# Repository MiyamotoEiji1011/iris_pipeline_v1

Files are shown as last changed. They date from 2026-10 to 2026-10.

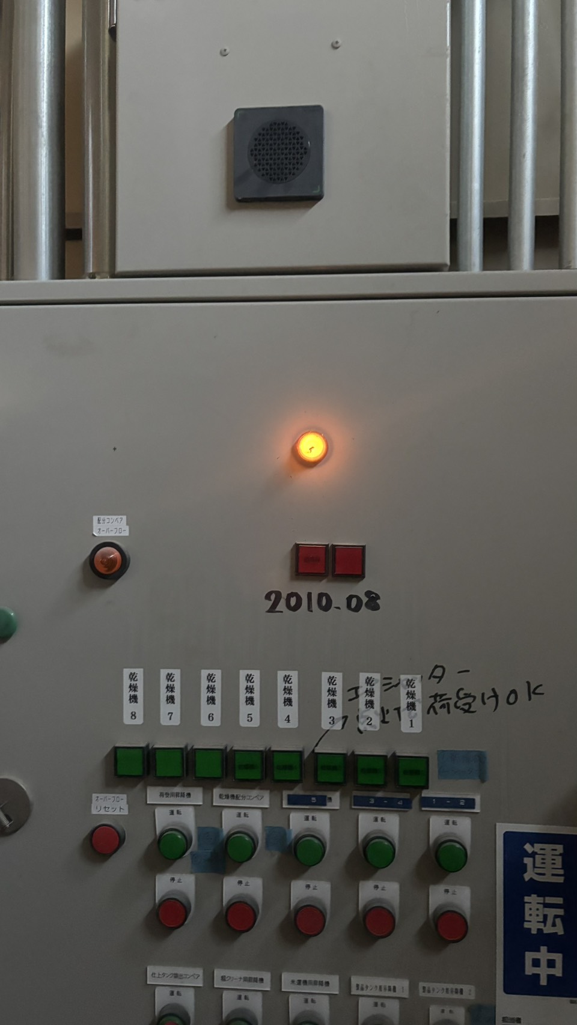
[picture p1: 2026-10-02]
画像/S__83599375_0.jpg

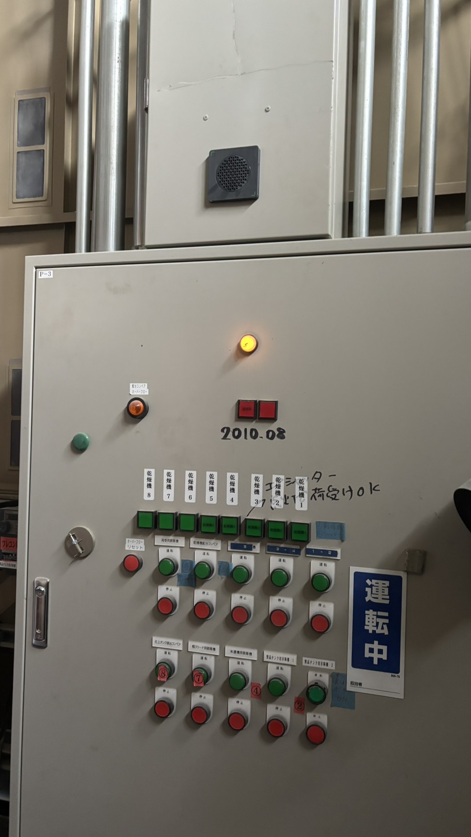
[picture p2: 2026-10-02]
画像/S__83599382_0.jpg

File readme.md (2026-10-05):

# iris pipeline v1
空調設備管理デバイス
各空調機（エアコン）の温度を計測し、空調設備の電力効率向上を目的として、必要に応じてミストを噴射し、銅管温度を低下させるデバイスです。
温度センサから取得した測定値をもとに電磁弁を自動制御し、設定された温度条件に応じてミストの噴射・停止を行います。

※温度センサについて
各空調機に2台のセンサを使用する。
銅管と空気の吸気部分の2か所に配置して温度を測定する。
電磁弁の制御に使用する値はwebアプリ側で切り替えれるようにする。

# 配線
## 温度センサ(DS18B20)
GPIO04=sensor_A1,sensor_A2
GPIO05=sensor_B1,sensor_B2
GPIO06=sensor_C1,sensor_C2

GPIO12=sensor_D1,sensor_D2
GPIO13=sensor_E1,sensor_E2
GPIO16=sensor_F1,sensor_F2

GPIO17=sensor_G1,sensor_G2
GPIO18=sensor_H1,sensor_H2
GPIO19=sensor_I1,sensor_I2

GPIO20=sensor_J1,sensor_J2
GPIO21=sensor_K1,sensor_K2
GPIO26=sensor_L1,sensor_L2
## 電磁バルブ(12V)
リレーモジュールに接続(8つ)
## リレーモジュール(リレー*8)
GPIO07=relay_A
GPIO08=relay_B
GPIO09=relay_C
GPIO10=relay_D
GPIO11=relay_E
GPIO22=relay_F
GPIO23=relay_G
GPIO24=relay_H
## LED
GPIO25=DAEMON_LED
GPIO27=API_LED
GPIO14=NETWORK_LED
## SW
GPIO15=Reset_SW

# webアプリ
githubPagesをもちいて、ラズパイ側のッデータの受け取りや設定の書き換えなどを行う。APIを使用してユーザーが任意のタイミングでリクエストができるようにする。常時通信は行わない。

# コード
## main
tools,systemを使用して制御を行う。

## tools
・read_temp_sensor.py
read_temp_sensor(GPIO)->list(float)
任意のGPIOの温度センサーの値を取得可能できる数取得し返す。
・write_relay_module.py
write_relay_module(GPIO,bool)->bool()
リレーモジュールのGPIOのHIGH/LOWを切り替える
・write_temp_date.py
write_temp_date()->xlsx
指定の形式で温度データを渡すことでエクセルファイル追加保存する。また、エクセルファイルの新規作成などの関数もある。
・write_log.py
write_log()->txt
各、処理のログなどをすべて時間とともに保存する。
最大1000行までのログを記載し、超える場合は古い記録と入れ替える。

## api
未定

## system
・read_network.py
ネットワーク接続状態を確認する。
・read_api.py
外部アプリからの接続や編集を管理
・read_reset_switch.py
デーモンを終了し、システムを再起動
・read_system.py
OSの状態を管理

## config
・attach_pin.json
各GPIOのピン設定などを名前付けして定義づける。main.pyは起動時にこのファイルから読み込んだPINを使用して制御を行う。また、温度センサーの識別IDも記載。
・date_config.json
データの読み取り間隔などデータの記録に関する定義を保存するファイル。
・process_config.json
各電磁弁の開閉温度の設定、各空調機の制御で銅管温度と吸気温度のどちらを設定しているのかを保存しているファイル。
・config
　githubなどのアカウント関係に紐づく値を管理

# raspi
cd ~/iris_pipeline_v1/raspi
git pull
source .venv/bin/activate
pip install -r requirements.txt

## git
cd ~/iris_pipeline_v1
git add .
git commit -m "update raspi code"
git push

## デーモン（systemd）

### 初回登録
```bash
sudo cp ~/iris_pipeline_v1/raspi/iris_pipeline.service /etc/systemd/system/
sudo systemctl daemon-reload
sudo systemctl enable iris_pipeline
sudo systemctl start iris_pipeline
```

### 状態確認
```bash
sudo systemctl status iris_pipeline
```

### ログ確認
```bash
journalctl -u iris_pipeline -f
```

### 停止 / 起動 / 再起動
```bash
sudo systemctl stop iris_pipeline
sudo systemctl start iris_pipeline
sudo systemctl restart iris_pipeline
```

### 自動起動の無効化
```bash
sudo systemctl disable iris_pipeline
```

### コード更新後の反映手順
```bash
cd ~/iris_pipeline_v1
git pull
sudo systemctl restart iris_pipeline
```

## システム監視デーモン（iris_system）

ネットワーク状態 LED と リセット SW を管理する独立デーモン。

### sudo reboot の許可設定（初回のみ）
```bash
sudo visudo
```
以下の行を末尾に追加して保存：
```
pi ALL=(ALL) NOPASSWD: /sbin/reboot
```

### 初回登録
```bash
sudo cp ~/iris_pipeline_v1/raspi/iris_system.service /etc/systemd/system/
sudo systemctl daemon-reload
sudo systemctl enable iris_system
sudo systemctl start iris_system
```

### 状態確認 / ログ
```bash
sudo systemctl status iris_system
journalctl -u iris_system -f
```

### 停止 / 起動 / 再起動
```bash
sudo systemctl stop iris_system
sudo systemctl start iris_system
sudo systemctl restart iris_system
```

### コード更新後の反映手順
```bash
cd ~/iris_pipeline_v1
git pull
sudo systemctl restart iris_system
```

# webapp
https://miyamotoeiji1011.github.io/iris_pipeline_v1/

# Tailscale
IPの確認
tailscale ip -4

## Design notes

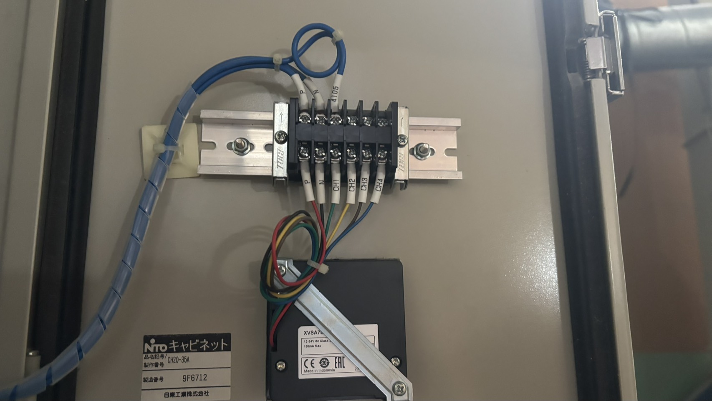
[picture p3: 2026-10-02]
画像/S__83599379_0.jpg

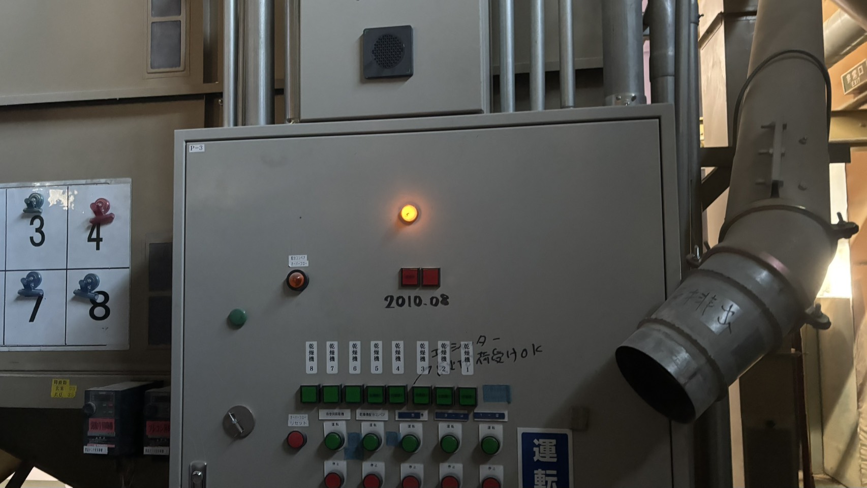
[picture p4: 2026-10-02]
画像/S__83599374_0.jpg

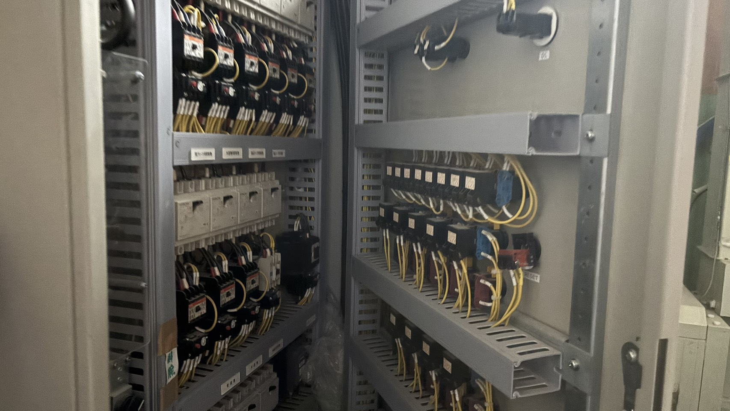
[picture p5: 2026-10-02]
画像/S__83599384_0.jpg

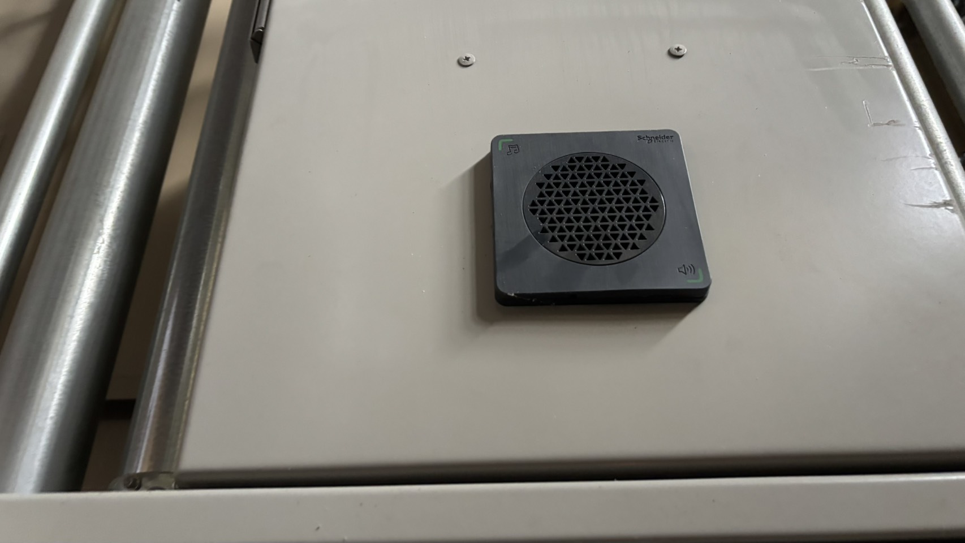
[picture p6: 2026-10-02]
画像/S__83599381_0.jpg

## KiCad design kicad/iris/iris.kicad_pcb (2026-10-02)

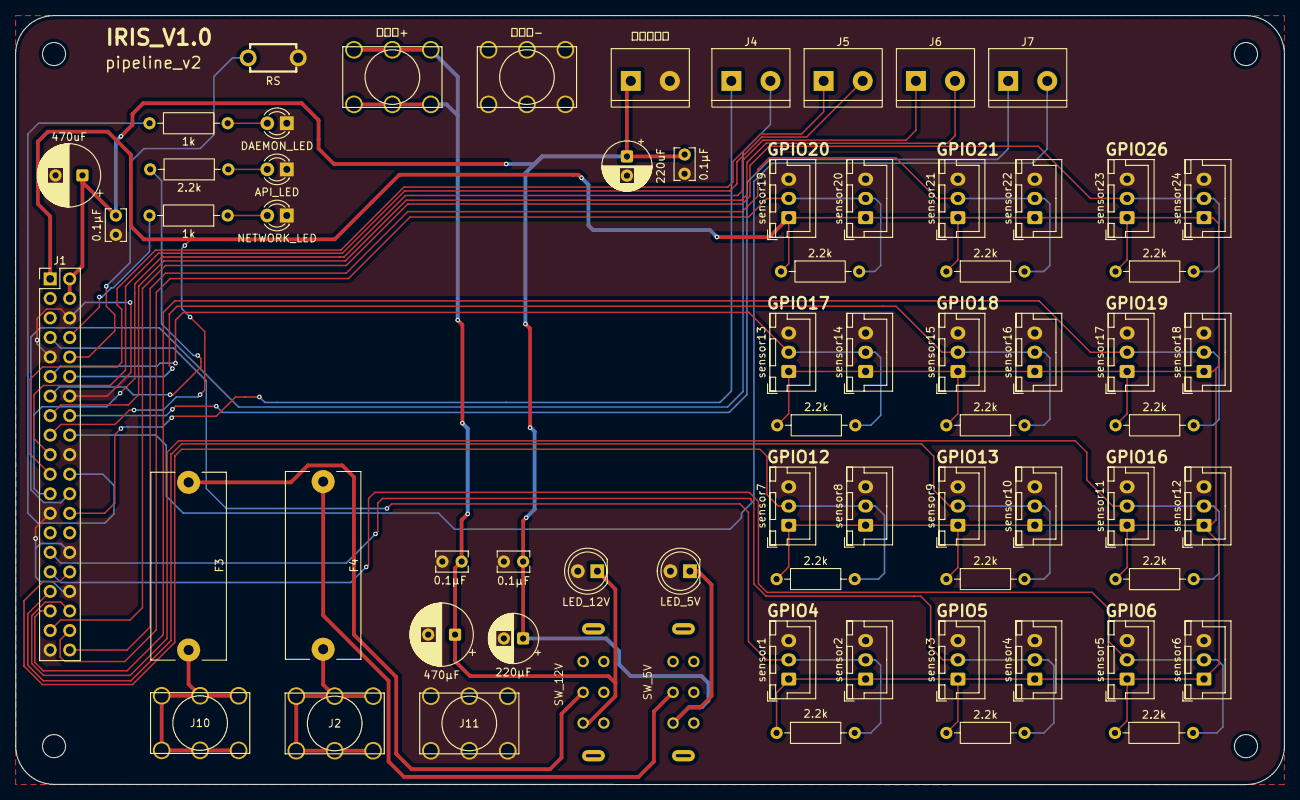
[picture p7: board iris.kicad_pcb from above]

Board: 2 copper layers, 165.0 x 100.0 mm, 68 parts (0 on the bottom side), 35 nets.

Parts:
0.1µF, 0.1µF#2, 0.1µF#3, 0.1µF#4: 0.1µF; C_Rect_L4.0mm_W2.5mm_P2.50mm
1k, 1k#2: 1k; R_Axial_DIN0207_L6.3mm_D2.5mm_P10.16mm_Horizontal
2.2k, 2.2k#2, 2.2k#3, 2.2k#4, 2.2k#5, 2.2k#6, 2.2k#7, 2.2k#8, 2.2k#9, 2.2k#10, 2.2k#11, 2.2k#12, 2.2k#13: 2.2k; R_Axial_DIN0207_L6.3mm_D2.5mm_P10.16mm_Horizontal
220uF: 220uF; CP_Radial_D6.3mm_P2.50mm
220µF: 220µF; CP_Radial_D6.3mm_P2.50mm
470uF: 470uF; CP_Radial_D8.0mm_P3.50mm
470µF: 470µF; CP_Radial_D8.0mm_P3.50mm
API_LED: API_LED; LED_D3.0mm
DAEMON_LED: DAEMON_LED; LED_D3.0mm
F3, F4: Fuse; Fuseholder_Cylinder-5x20mm_MF-563
J1: Conn_02x20_Odd_Even; PinHeader_2x20_P2.54mm_Vertical
J2: 電源5V; PCB-20(632)F
J4, J5, J6, J7: 信号ターミナル; TerminalBlock_Alphaplus_TB111-2-2-E-1-1_1x02_P5.08_Horizont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
J10: 電源12V; PCB-20(632)F
J11: 電源GND; PCB-20(632)F
LED_5V: OSG8NU5B64A-5V; LED_D5.0mm
LED_12V: OSG8NU5B64A-12V; LED_D5.0mm
NETWORK_LED: NETWORK_LED; LED_D3.0mm
RS: SW_Push; sw_TVBP06-B043CB-B
SW_5V, SW_12V: SW_DPDT_x2; SS22F06G5-G
sensor1, sensor2, sensor3, sensor4, sensor5, sensor6, sensor7, sensor8, sensor9, sensor10, sensor11, sensor12, sensor13, sensor14, sensor15, sensor16, sensor17, sensor18, sensor19, sensor20, sensor21, sensor22, sensor23, sensor24: B3B-XH-A(LF)(SN); JST_XH_B3B-XH-A_1x03_P2.50mm_Vertical
リレー電源: リレー電源ターミナル; TerminalBlock_Alphaplus_TB111-2-2-E-1-1_1x02_P5.08_Horizont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
電磁弁+: 電磁弁+; PCB-20(632)F
電磁弁-: 電磁弁-; PCB-20(632)F

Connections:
+3V3: 2.2k.1, 2.2k#2.1, 2.2k#3.1, 2.2k#4.1, 2.2k#6.1, 2.2k#7.1, 2.2k#8.1, 2.2k#9.1, 2.2k#10.1, 2.2k#11.1, 2.2k#12.1, 2.2k#13.1, J1.1, J1.17, sensor1.1, sensor2.1, sensor3.1, sensor4.1, sensor5.1, sensor6.1, sensor7.1, sensor8.1, sensor9.1, sensor10.1, sensor11.1, sensor12.1, sensor13.1, sensor14.1, sensor15.1, sensor16.1, sensor17.1, sensor18.1, sensor19.1, sensor20.1, sensor21.1, sensor22.1, sensor23.1, sensor24.1
+5V: 0.1µF#2.1, 0.1µF#3.1, 0.1µF#4.1, 220uF.1, 220µF.1, 470uF.1, J1.2, J1.4, LED_5V.1 (K), SW_5V.1 (A), リレー電源.1
+12V: 0.1µF.1, 470µF.1, LED_12V.1 (K), SW_12V.1 (A), 電磁弁+.1
GND: 0.1µF.2, 0.1µF#2.2, 0.1µF#3.2, 0.1µF#4.2, 220uF.2, 220µF.2, 470uF.2, 470µF.2, API_LED.1 (K), DAEMON_LED.1 (K), J1.6, J1.9, J1.14, J1.20, J1.25, J1.30, J1.34, J1.39, J11.1, LED_5V.2 (A), LED_12V.2 (A), NETWORK_LED.1 (K), RS.2, sensor1.3, sensor2.3, sensor3.3, sensor4.3, sensor5.3, sensor6.3, sensor7.3, sensor8.3, sensor9.3, sensor10.3, sensor11.3, sensor12.3, sensor13.3, sensor14.3, sensor15.3, sensor16.3, sensor17.3, sensor18.3, sensor19.3, sensor20.3, sensor21.3, sensor22.3, sensor23.3, sensor24.3, リレー電源.2, 電磁弁-.1
GPIO4: 2.2k#9.2, J1.7, sensor1.2, sensor2.2
GPIO5: 2.2k.2, J1.29, sensor3.2, sensor4.2
GPIO6: 2.2k#12.2, J1.31, sensor5.2, sensor6.2
GPIO7: J1.26, J4.1
GPIO8: J1.24, J4.2
GPIO9: J1.21, J5.1
GPIO10: J1.19, J5.2
GPIO11: J1.23, J6.1
GPIO12: 2.2k#7.2, J1.32, sensor7.2, sensor8.2
GPIO13: 2.2k#2.2, J1.33, sensor9.2, sensor10.2
GPIO14: 1k#2.2, J1.8
GPIO16: 2.2k#4.2, J1.36, sensor11.2, sensor12.2
GPIO17: 2.2k#11.2, J1.11, sensor13.2, sensor14.2
GPIO18: 2.2k#6.2, J1.12, sensor15.2, sensor16.2
GPIO19: 2.2k#10.2, J1.35, sensor17.2, sensor18.2
GPIO20: 2.2k#8.2, J1.38, sensor19.2, sensor20.2
GPIO21: 2.2k#3.2, J1.40, sensor21.2, sensor22.2
GPIO22: J1.15, J6.2
GPIO23: J1.16, J7.1
GPIO24: J1.18, J7.2
GPIO25: 1k.2, J1.22
GPIO26: 2.2k#13.2, J1.37, sensor23.2, sensor24.2
GPIO27: 2.2k#5.2, J1.13
unnamed: 1k.1, DAEMON_LED.2 (A)
unnamed: 2.2k#5.1, API_LED.2 (A)
unnamed: 1k#2.1, NETWORK_LED.2 (A)
unnamed: J1.10, RS.1
unnamed: F4.1, J2.1
unnamed: F3.1, J10.1
unnamed: F4.2, SW_5V.2 (B)
unnamed: F3.2, SW_12V.2 (B)

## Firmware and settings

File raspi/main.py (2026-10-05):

import RPi.GPIO as GPIO  # type: ignore
import json
import os
import threading
import time
from datetime import datetime
from config.units import UNITS
from config.data_config import (
    CONTROL_INTERVAL, CONFIG_POLL_INTERVAL, RECORD_INTERVAL,
    STATUS_PUSH_INTERVAL, DATA_PUSH_INTERVAL,
)
from tools.read_temp_sensor import read_temp_sensor
from tools.write_relay_module import write_relay_module
from tools.write_csv import append_csv
from tools.fetch_process_config import fetch_process_config
from tools.push_status_json import push_status_json
from tools.git_push_data import git_push_data

_PROCESS_CONFIG_PATH = os.path.join(os.path.dirname(__file__), "config/process_config.json")
_DATA_DIR            = os.path.join(os.path.dirname(__file__), "../data")

DAEMON_LED_GPIO = 25
API_LED_GPIO    = 27

_applied_version: int       = 0
_pending_config:  dict | None = None
_api_led_stop:    threading.Event | None = None


def log(msg):
    print(f"[{datetime.now().strftime('%H:%M:%S')}] {msg}")


# ---------------------------------------------------------------------------
# API LED（GPIO27）点滅制御
# ---------------------------------------------------------------------------

def _blink_worker(stop_event: threading.Event):
    """別スレッドで API_LED を 0.3秒周期で点滅させる。"""
    while not stop_event.is_set():
        GPIO.output(API_LED_GPIO, True)
        stop_event.wait(0.3)
        GPIO.output(API_LED_GPIO, False)
        stop_event.wait(0.3)
    GPIO.output(API_LED_GPIO, False)


def start_api_led():
    global _api_led_stop
    if _api_led_stop is not None:
        return
    _api_led_stop = threading.Event()
    threading.Thread(target=_blink_worker, args=(_api_led_stop,), daemon=True).start()


def stop_api_led():
    global _api_led_stop
    if _api_led_stop is None:
        return
    _api_led_stop.set()
    _api_led_stop = None


# ---------------------------------------------------------------------------
# config 適用
# ---------------------------------------------------------------------------

def _apply_units_config(config: dict, apply_manual: bool = True):
    """
    config dict の内容を UNITS に適用する。
    モード変更時はリレーを安全にOFF（Desired State → Actual State の橋渡し）。

    Args:
        config:       process_config.json の内容
        apply_manual: False の場合、手動モードでも relay を ON しない（起動時用）
    """
    global _applied_version
    for unit_name, unit in UNITS.items():
        if unit_name not in config.get("units", {}):
            continue
        cfg      = config["units"][unit_name]
        new_mode = cfg["mode"]
        old_mode = unit["mode"]

        # モードが変わるときは先にリレーをOFF
        if old_mode is not None and old_mode != new_mode:
            write_relay_module(unit["relay_gpio"], False)
            unit["relay_state"] = False
            log(f"  ユニット{unit_name} モード変更 ({old_mode}→{new_mode}) 強制OFF")

        unit["label"]          = cfg.get("label", unit_name)
        unit["temp_on"]        = cfg["temp_on"]
        unit["temp_off"]       = cfg["temp_off"]
        unit["mode"]           = cfg["mode"]
        unit["manual_command"] = cfg["manual_command"]
        unit["control_sensor"] = cfg.get("control_sensor", "銅管部温度")

        # 手動モード: manual_command を即時適用（起動時は常にOFF）
        if new_mode == "manual":
            state = (cfg["manual_command"] == "ON") and apply_manual
            write_relay_module(unit["relay_gpio"], state)
            unit["relay_state"] = state
            cmd_str = "ON" if state else "OFF"
            log(f"  ユニット{unit_name} 手動コマンド適用: {cmd_str}")

    _applied_version = config.get("version", _applied_version)
    log(f"config v{_applied_version} 適用完了")


def load_process_config():
    """起動時: ローカルの process_config.json を読み込む（手動コマンドは適用しない）。"""
    with open(_PROCESS_CONFIG_PATH) as f:
        config = json.load(f)
    _apply_units_config(config, apply_manual=False)


def check_and_apply_config():
    """GitHub から設定を取得し、バージョンが新しければ pending_config にセットする。"""
    global _pending_config
    new_config = fetch_process_config()
    if new_config is None:
        return
    if new_config.get("version", 0) > _applied_version:
        _pending_config = new_config
        log(f"新しいconfig検知 v{new_config['version']} → 次の制御サイクルで適用")


# ---------------------------------------------------------------------------
# GPIO
# ---------------------------------------------------------------------------

def cleanup():
    stop_api_led()
    try:
        GPIO.output(DAEMON_LED_GPIO, False)
        GPIO.output(API_LED_GPIO, False)
    except RuntimeError:
        pass
    GPIO.cleanup()
    log("GPIO クリーンアップ完了")


def setup():
    cleanup()
    GPIO.setmode(GPIO.BCM)
    GPIO.setup(DAEMON_LED_GPIO, GPIO.OUT, initial=GPIO.LOW)
    GPIO.setup(API_LED_GPIO,    GPIO.OUT, initial=GPIO.LOW)
    GPIO.output(DAEMON_LED_GPIO, True)
    log("GPIO セットアップ完了")
    load_process_config()


# ---------------------------------------------------------------------------
# センサ・制御
# ---------------------------------------------------------------------------

def temp_sensor() -> list[dict]:
    log("----温度センサ----")
    results = []
    for unit_name, unit in UNITS.items():
        for r in read_temp_sensor(unit["sensors"]):
            unit[r["role"]] = r["temp"]
            temp_str = f"{r['temp']:.3f} C" if r["temp"] is not None else "読み取り失敗"
            log(f"  ユニット{unit_name}  {r['name']:12s}  {r['role']}  {temp_str}")
            results.append(r)
    return results


def control_units():
    """自動モードは温度閾値で制御。手動モードは pending_config 適用時に処理済みのためスキップ。"""
    log("----電磁弁 制御----")
    for unit_name, unit in UNITS.items():
        if unit["mode"] != "auto":
            log(f"  ユニット{unit_name} 手動操作")
            continue

        sensor   = unit.get("control_sensor", "銅管部温度")
        temp     = unit[sensor]
        temp_on  = unit["temp_on"]
        temp_off = unit["temp_off"]

        if temp is None or temp_on is None or temp_off is None:
            log(f"  ユニット{unit_name} データ不足のためスキップ")
            continue

        if temp >= temp_on and not unit["relay_state"]:
            if write_relay_module(unit["relay_gpio"], True):
                unit["relay_state"] = True
            log(f"  ユニット{unit_name} ON  ({sensor} {temp:.3f}C >= {temp_on}C)")
        elif temp <= temp_off and unit["relay_state"]:
            if write_relay_module(unit["relay_gpio"], False):
                unit["relay_state"] = False
            log(f"  ユニット{unit_name} OFF ({sensor} {temp:.3f}C <= {temp_off}C)")
        else:
            log(f"  ユニット{unit_name} 保持 ({sensor} {temp:.3f}C, relay={'ON' if unit['relay_state'] else 'OFF'})")


def record_csv():
    append_csv(UNITS, _DATA_DIR)
    log("CSV 記録完了")


# ---------------------------------------------------------------------------
# メインループ
# ---------------------------------------------------------------------------

def main():
    global _pending_config
    setup()

    last_control     = 0.0
    last_config_poll = 0.0
    last_record      = 0.0
    last_status_push = 0.0
    last_data_push   = 0.0

    try:
        while True:
            now = time.time()

            # ① センサ・制御（CONTROL_INTERVAL）
            if now - last_control >= CONTROL_INTERVAL:
                last_control = now
                temp_sensor()
                control_units()
                # 制御サイクル完了後に pending config を安全に適用
                if _pending_config is not None:
                    _apply_units_config(_pending_config)
                    _pending_config = None

            # ② GitHub 設定確認（CONFIG_POLL_INTERVAL）
            if now - last_config_poll >= CONFIG_POLL_INTERVAL:
                last_config_poll = now
                start_api_led()
                try:
                    check_and_apply_config()
                finally:
                    stop_api_led()

            # ③ CSV 記録（RECORD_INTERVAL）
            if now - last_record >= RECORD_INTERVAL:
                last_record = now
                record_csv()

            # ④ status.json 更新（STATUS_PUSH_INTERVAL）
            if now - last_status_push >= STATUS_PUSH_INTERVAL:
                last_status_push = now
                log("----status push----")
                start_api_led()
                try:
                    push_status_json(UNITS, _applied_version)
                finally:
                    stop_api_led()

            # ⑤ CSV git push（DATA_PUSH_INTERVAL）
            if now - last_data_push >= DATA_PUSH_INTERVAL:
                last_data_push = now
                log("----git push----")
                start_api_led()
                try:
                    git_push_data()
                finally:
                    stop_api_led()

            time.sleep(0.1)

    except KeyboardInterrupt:
        log("停止しました")
    finally:
        cleanup()


if __name__ == "__main__":
    main()

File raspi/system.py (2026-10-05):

"""
システム監視デーモン（main.py とは独立して動作）

・NETWORK_LED (GPIO14): ネットワーク接続中=点灯、切断=消灯
・Reset_SW   (GPIO15): 3秒長押しでラズパイを再起動
"""

import os
import socket
import subprocess
import threading
import time
from datetime import datetime

import RPi.GPIO as GPIO  # type: ignore

NETWORK_LED_GPIO = 14
RESET_SW_GPIO    = 15

NET_CHECK_INTERVAL = 10   # ネットワーク確認間隔（秒）
REBOOT_HOLD_SEC    = 3    # リセットSW の長押し判定時間（秒）


def log(msg):
    print(f"[{datetime.now().strftime('%H:%M:%S')}] [system] {msg}", flush=True)


# ---------------------------------------------------------------------------
# ネットワーク確認
# ---------------------------------------------------------------------------

def _is_network_available() -> bool:
    """8.8.8.8:53 への TCP 接続でインターネット疎通を確認する。"""
    try:
        sock = socket.socket(socket.AF_INET, socket.SOCK_STREAM)
        sock.settimeout(3)
        sock.connect(("8.8.8.8", 53))
        sock.close()
        return True
    except OSError:
        return False


def _network_monitor():
    """バックグラウンドスレッド: 定期的にネットワークを確認して LED を制御する。"""
    prev = None
    while True:
        connected = _is_network_available()
        if connected != prev:
            GPIO.output(NETWORK_LED_GPIO, connected)
            log(f"ネットワーク: {'接続中' if connected else '切断'}")
            prev = connected
        time.sleep(NET_CHECK_INTERVAL)


# ---------------------------------------------------------------------------
# リセットスイッチ監視
# ---------------------------------------------------------------------------

def _watch_reset_sw():
    """
    メインスレッドでリセット SW を監視する。
    プルアップ接続（押下で LOW）を前提とする。
    3秒長押しで sudo reboot を実行。
    """
    while True:
        if GPIO.input(RESET_SW_GPIO) == GPIO.LOW:
            log(f"リセットSW 押下検知 ({REBOOT_HOLD_SEC}秒ホールドで再起動)")
            press_start = time.time()
            while GPIO.input(RESET_SW_GPIO) == GPIO.LOW:
                if time.time() - press_start >= REBOOT_HOLD_SEC:
                    log("再起動実行")
                    _cleanup()
                    subprocess.run(["sudo", "reboot"], check=False)
                    return
                time.sleep(0.05)
            log("リセットSW 短押し（無視）")
        time.sleep(0.05)


# ---------------------------------------------------------------------------
# GPIO セットアップ / クリーンアップ
# ---------------------------------------------------------------------------

def _setup():
    GPIO.setmode(GPIO.BCM)
    GPIO.setup(NETWORK_LED_GPIO, GPIO.OUT, initial=GPIO.LOW)
    GPIO.setup(RESET_SW_GPIO,    GPIO.IN,  pull_up_down=GPIO.PUD_UP)
    log("GPIO セットアップ完了")


def _cleanup():
    try:
        GPIO.output(NETWORK_LED_GPIO, False)
    except RuntimeError:
        pass
    GPIO.cleanup()
    log("GPIO クリーンアップ完了")


# ---------------------------------------------------------------------------
# エントリポイント
# ---------------------------------------------------------------------------

def main():
    _setup()

    threading.Thread(target=_network_monitor, daemon=True).start()
    log("システム監視開始")

    try:
        _watch_reset_sw()
    except KeyboardInterrupt:
        log("停止しました")
    finally:
        _cleanup()


if __name__ == "__main__":
    main()
